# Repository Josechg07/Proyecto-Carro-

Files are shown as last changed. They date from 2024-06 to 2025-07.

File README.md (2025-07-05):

# SONICAR
# Logbook

This repository contains information about the sonicar team's robot for the 2025 World Robot Olympiad (WRO) Future Engineers competition. The design of the robot was taked from thingiverse, but was adapted to the necesities of the team.

# Team

### José Ricardo Chacón

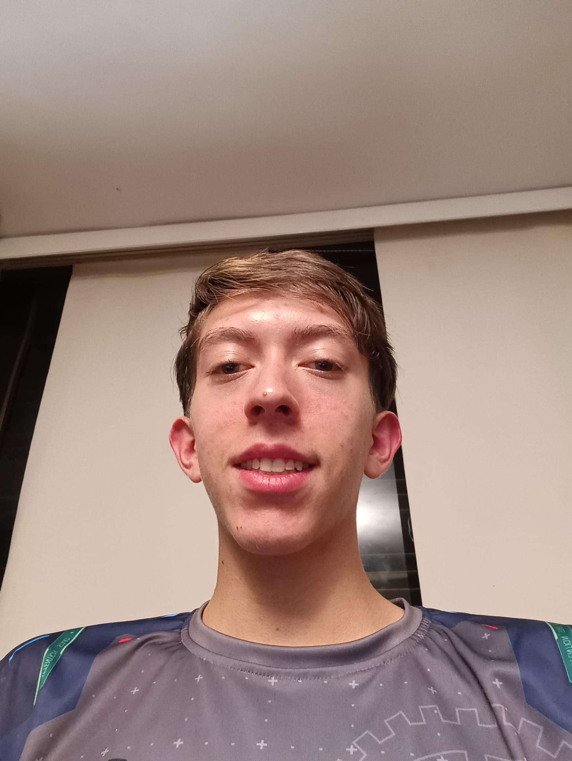
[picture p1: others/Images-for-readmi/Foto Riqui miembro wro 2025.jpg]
Photo member José Ricardo Chacón


Hey there!! I'm José Ricardo from Venezuela. This is my second time participating in the WRO on the Future Engineers category and this have been too much amazing!! On the first time, last year, my team and I got the opportunity to go to the competition on Italy because we got the first place in the regional leaderboard. This is an entire new experience, even that is the second time!! Creating this tipe of robot, obtaining new knowledge, meeting new people, is an incredible experience that I love. Is incredible what we can obtain with this tipe of challenges, and I'm ready to beat this!! Also, I like F1, cars, robots, program, and the tennis.

### Andrés José Casenave

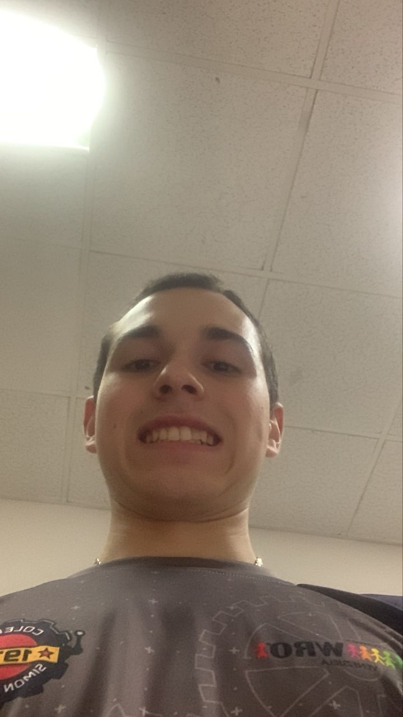
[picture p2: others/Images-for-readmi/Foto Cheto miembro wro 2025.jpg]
Photo member Andrés José Casenave


Hello! I’m Andrés from Venezuela, and this is my second time participating in the WRO Future Engineers category. Last year, my team and I got first place in the regional leaderboard. We qualified for the National Contest, where we had the opportunity to meet new people and see their way of confronting the challenge. I like robotics, cars, motorcycles, and basically anything with an engine on it.

### Juán Andrés Perez

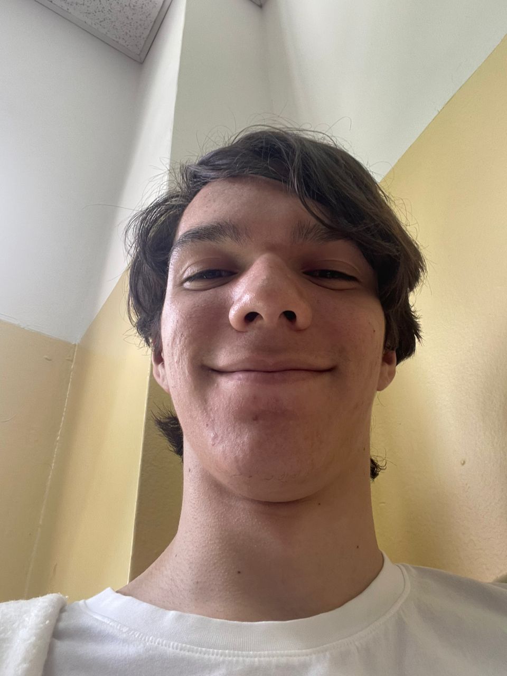
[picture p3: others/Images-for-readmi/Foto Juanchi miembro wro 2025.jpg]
Photo member Juán Andrés Perez


Hey, I'm Juan Pérez from Venezuela! This is my first time joining the WRO on the Future Engineers category and I am having a blast! I had never tried it before, but after starting, creating this robot has been an amazing experience. I love challenging myself! From crosswords to chess, you name it, and this whole experience feels like an even bigger challenge I'm ready to beat!

# Photo Team

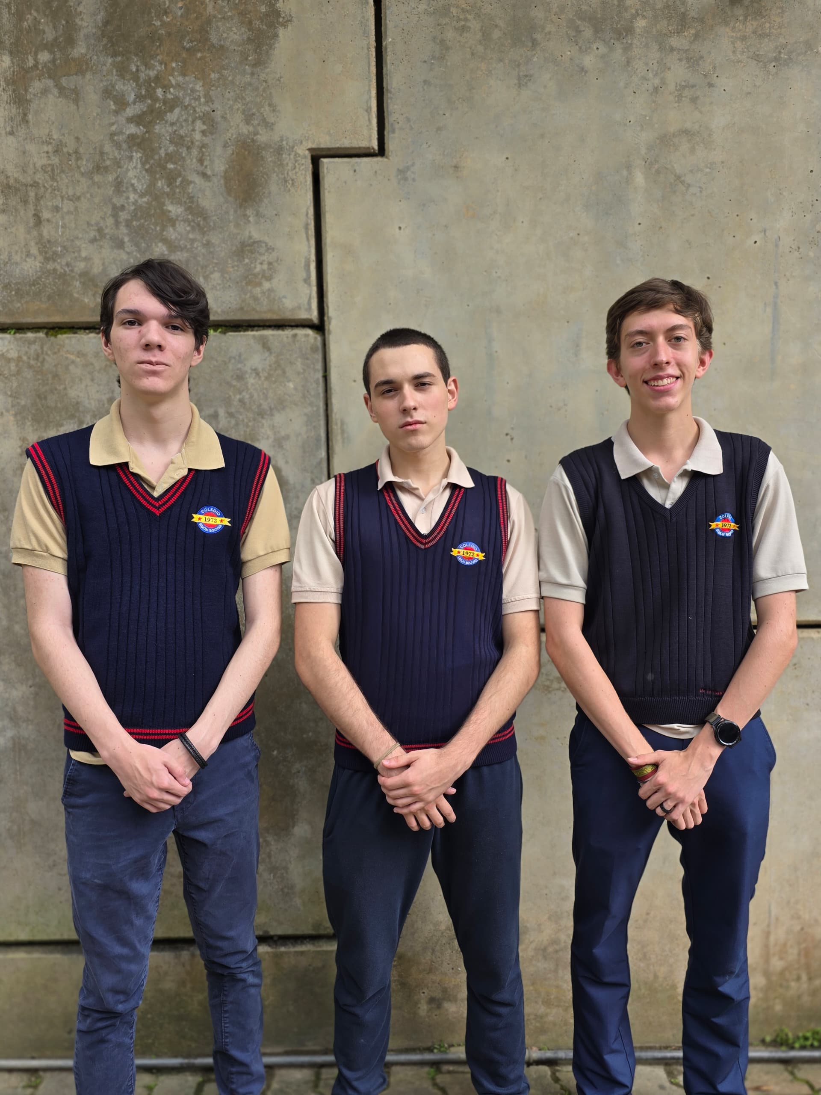
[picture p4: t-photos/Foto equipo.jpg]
Photo Team


# Challenge
The WRO 2024 Future Engineers – Autonomous Vehicle Challenge invites participants to conceptualize, construct, and program a robotic car capable of navigating a race track without human intervention. The layout of the track changes each round, requiring the robot to adapt in real-time. The challenge is divided into two core components: completing multiple laps while avoiding randomly placed obstacles, and executing an accurate parallel parking maneuver.

Participants are encouraged to apply advanced engineering principles including computer vision, sensor integration, and motion control, with a strong emphasis on innovation, precision, and system reliability.

This competition highlights essential stages of the engineering cycle, such as:

- Vehicle Dynamics: Designing effective and reliable mobility systems.

- Obstacle Navigation: Implementing strategies to identify and respond to traffic markers (red and green indicators) in compliance with event rules.

- Project Documentation: Demonstrating the development process, design rationale, and teamwork through transparent and collaborative repositories, such as GitHub.

Teams are evaluated not only on their robot's performance during the rounds but also on the clarity and depth of their engineering documentation and the ingenuity of their solution. The challenge aims to spark interest in STEM fields by offering hands-on experience in robotics, problem-solving, and collaborative innovation.

Discover more about the challenge by visiting the official site, or [*here*](https://wro-association.org/wp-content/uploads/WRO-2025-Future-Engineers-Self-Driving-Cars-General-Rules.pdf)

# Photos of the robot eustakio

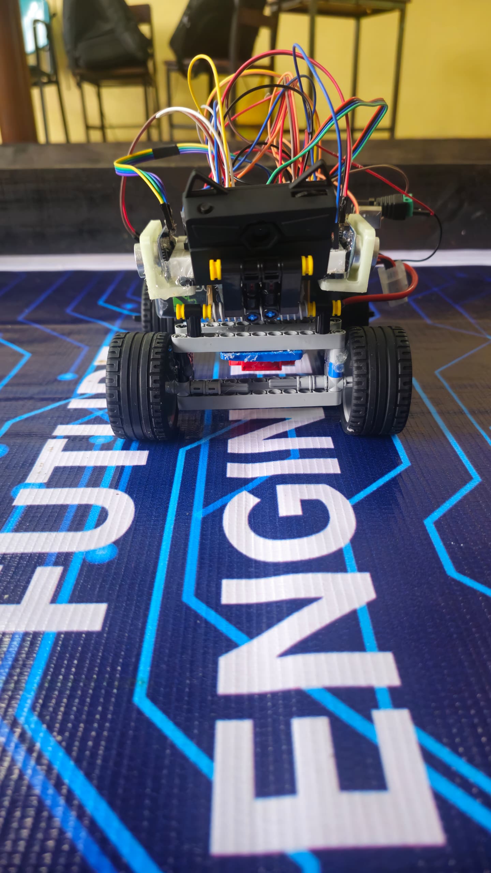
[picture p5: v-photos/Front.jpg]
Front
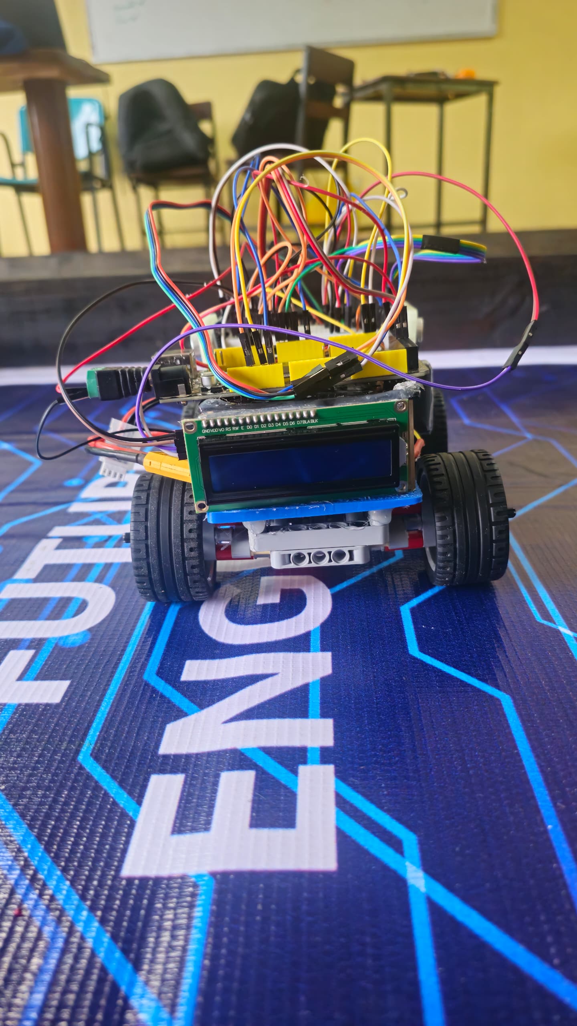
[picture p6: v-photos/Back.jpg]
Back
|  |  |
|:--:|:--:|
| Front | Back |

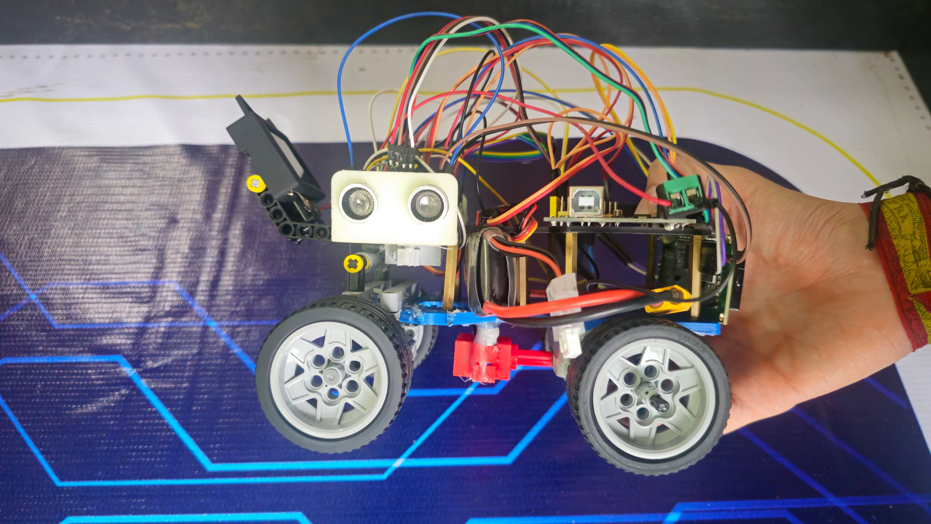
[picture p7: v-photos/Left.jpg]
Left
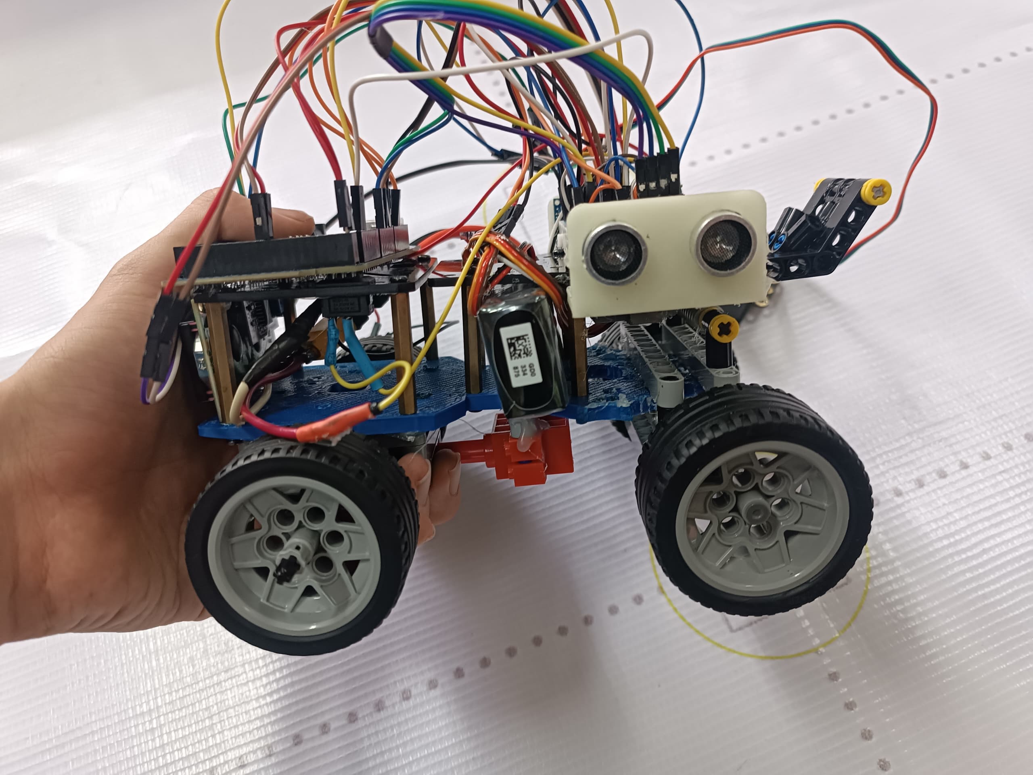
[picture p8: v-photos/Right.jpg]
Right
|  |  |
|:--:|:--:|
| Left | Right |

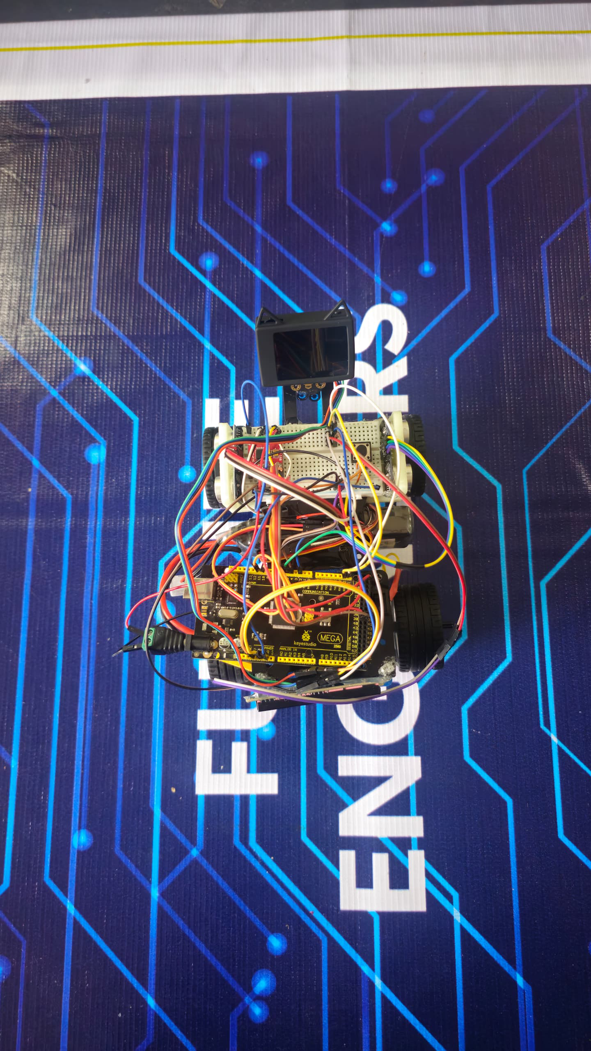
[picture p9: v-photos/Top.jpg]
Top
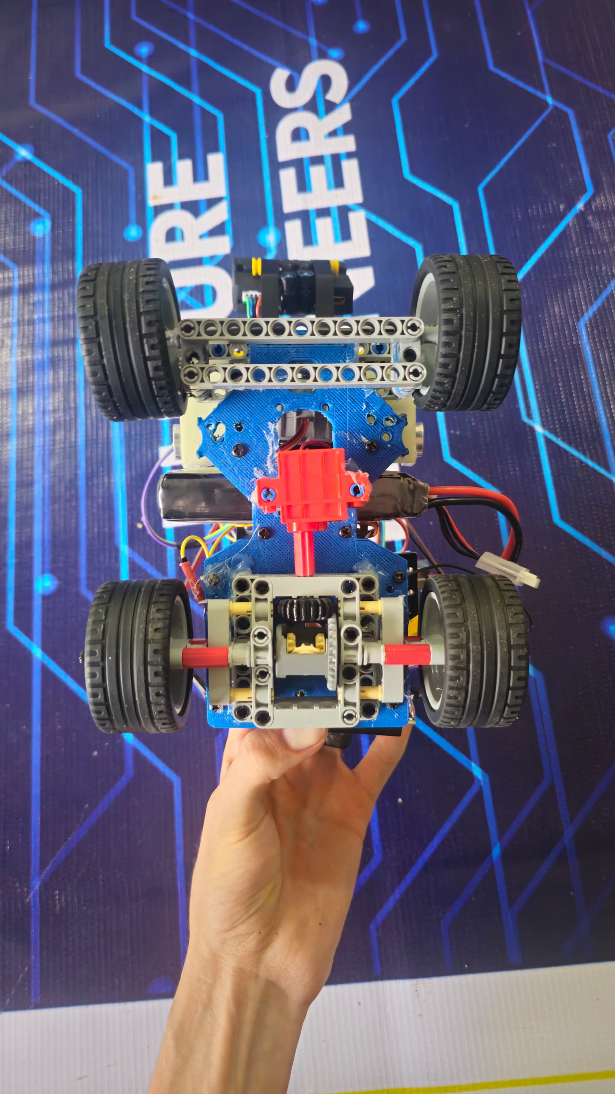
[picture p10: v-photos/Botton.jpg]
Botton
|  |  |
|:--:|:--:|
| Top | Botton |

# Video of our robot on: [*Youtube*](https://youtu.be/cRhCX8bQ4Iw)

# Mechanic Management

Desde la batería se derivan dos conductores: uno correspondiente al polo negativo (GND) y otro al polo positivo (V+). El conductor positivo está interrumpido por un interruptor mecánico, que actúa como un control de encendido, permitiendo o bloqueando el flujo de corriente hacia el resto del sistema.

Posterior al interruptor, el conductor se conecta al terminal VM (Voltage Motor) del puente H, responsable de alimentar los motores. Desde esta misma línea de alimentación, se deriva una conexión hacia el pin VIN del Arduino, que permite suministrar energía a la placa. El conductor negativo de la batería se conecta directamente al pin GND del Arduino, cerrando así el circuito de alimentación de la placa.

Adicionalmente, en el puente H se conecta un pin de alimentación (VCC) hacia la línea positiva de la protoboard para alimentar los componentes de lógica interna del puente.

El puente H dispone de tres pines de control: PWM A, IN1 e IN2.

PWM A está conectado al pin digital 10 del Arduino y permite la modulación por ancho de pulso (PWM) para el control de velocidad.

IN1 e IN2, conectados a los pines 12 y 13 respectivamente, determinan la dirección de rotación del motor conectado al canal A.

Las salidas del puente H (OUT1 y OUT2) están conectadas directamente al motor de corriente continua. Estas salidas permiten controlar el sentido y velocidad del motor en función de las señales de entrada enviadas desde el microcontrolador.

Finalmente, el motor está acoplado a las ruedas mediante un eje común que atraviesa un sistema de diferencial mecánico, el cual optimiza la maniobrabilidad del vehículo en curvas, distribuyendo el par de manera eficiente entre las ruedas y reduciendo el desgaste prematuro de las mismas.

### Motor DC Lego

<table border="1" cellspacing="0" cellpadding="10">
  <tr>
    <td width="50%" align="center">
      
    </td>
    <td width="50%" valign="top">
      <b>Specifications:</b>
      <ul>
        <li><b>Voltage:</b> 4.8V</li>
        <li><b>Gear Ratio:</b> 1:48</li>
        <li><b>Speed:</b> 650 ± 31% rpm</li>
        <li><b>Torque:</b> 1.2 ± kg·cm</li>
        <li><b>Weight:</b> 30g</li>
      </ul>
    </td>
  </tr>
</table>

A direct current (DC) motor runs on DC power. In this project, it propels the vehicle. The motor’s speed and direction are controlled via the L298 module, allowing the car to move forward or backward as needed. DC motors are known for their simplicity and efficiency, making them a popular choice in robotics.

### Motor Driver

<table border="1" cellspacing="0" cellpadding="10">
  <tr>
    <td width="50%" align="center">
      
    </td>
    <td width="50%" valign="top">
      <b>Specifications:</b>
      <ul>
        <li><b>Power supply voltage:</b> VM = 15V max, VCC = 2.7-5.5V</li>
        <li><b>Output current:</b> lout = 1.2A (average) / 3.2 A (peak) </li>
        <li><b>Standby control to save power</b></li>
        <li><b>CW/CCW/short-brake/stop motor control modes</b></li>
        <li><b>Built-in thermal shutdown cirtuit and low-voltage</b></li>
      </ul>
    </td>
  </tr>
</table>

The L298N motor driver controls the speed and direction of a DC motor. It receives signals from the Arduino and translates them into commands that the motor can understand, allowing for precise propulsion control. The L298N is a dual H-Bridge driver capable of handling two DC motors, but this project only uses one. Its ability to handle high voltages and currents makes it ideal for small-scale robotic and car projects.

### Steering

### Servo Motor

<table border="1" cellspacing="0" cellpadding="10">
  <tr>
    <td width="50%" align="center">
      
    </td>
    <td width="50%" valign="top">
      <b>Specifications:</b>
      <ul>
        <li><b>Rotation angle:</b> 270° </li>
        <li><b>Operating speed:</b> 0.12 ± 20% sec/60° at 4.8V </li>
        <li><b>Stall torque:</b> 1.8 kg·cm (6V) </li>
        <li><b>Weight:</b> 12.5g </li>
      </ul>
    </td>
  </tr>
</table>

A servo motor is used to control the vehicle’s direction. Servos are precision motors that rotate to specific angles, ideal for tasks requiring accurate movements. In this project, the servo is used to steer the front wheels, allowing the vehicle to change direction when obstacles are detected. Servo motors are essential in robotics for their precise control.

### Chasis

Here are the top view of the internal and external measurements, and .stl file of the chassis 3D. The design of the robot was personalized for our necessities of the competition.

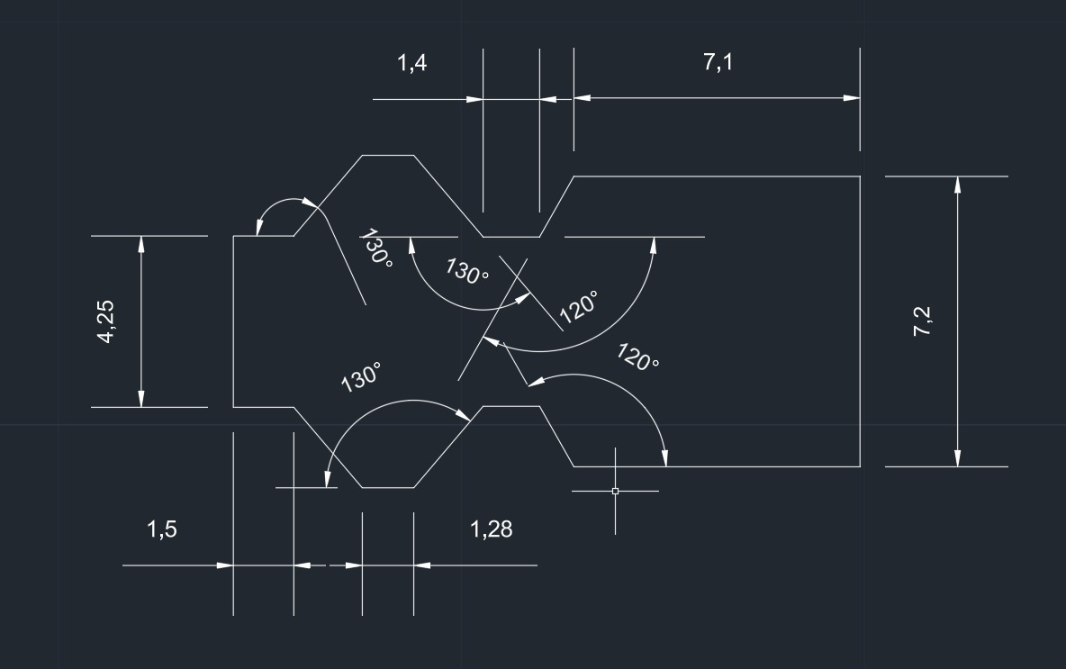
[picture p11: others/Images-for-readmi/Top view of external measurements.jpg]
Photo top view of the external measurements of the chassis 3D


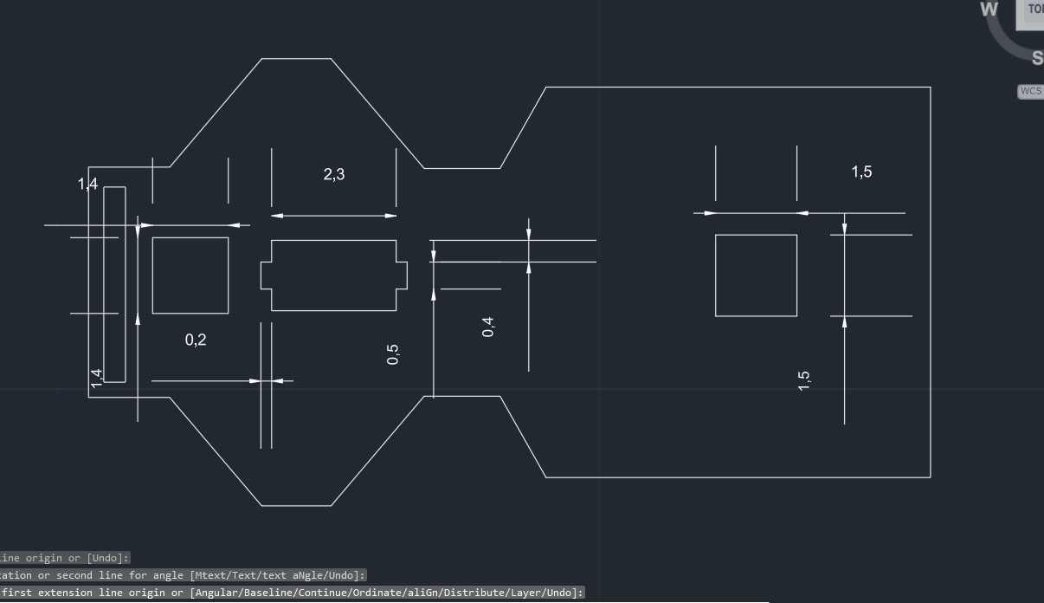
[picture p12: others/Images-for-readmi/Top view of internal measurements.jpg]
Photo top view of the internal measurements of the chassis 3D


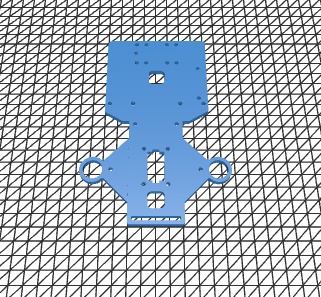
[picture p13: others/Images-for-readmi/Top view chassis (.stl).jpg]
Photo top view of the .stl file of the chassis 3D


### Creation of the Robot

Here are information about the process of creation of the robot of the team and images of the same:

Para armar el carro juntamos diversas piezas de distintas partes, algunas fueron diseñadas en 3D e impresas por nosotros, algunas pocas fueron timadas de kits de carros y otras piezas fueron armadas con LEGO. Originalmente el carro contaba con un sistema de giro con brazos rotulados a los extremos pero al ver que nos presentaba problemas en los giros cambiamos a un sistema con brazos impresos en 3D que posteriormente nos presentaron problemas debido a un punto muerto que tenían lo que permitía el giro libre de las ruedas haciendo que se tambaleara de un lado a otro y por último armamos un sistema de giro con LEGO que resultó ser más exacto y preciso al tomar curvas.

Para el sistema de potencia el carro contaba con un motor de DC  que iba conectado a un engranaje  que a su vez estaba conectado a un eje que se unía a las ruedas proporcionándoles la potencia necesaria para moverse; sin embargo, este sistema fue cambiado ya que el carro al ser muy pequeño y tener las ruedas muy grandes, en las curvas perdía velocidad y dejaba de avanzar, por lo que más adelante fue reemplazado por un sistema de propulsión en base a LEGO, en este sistema de agregó un diferencial mecánico lo que permitía a las ruedas traseras girar a distintas revoluciones, eliminando así el problema de la pérdida de velocidad en las curvas

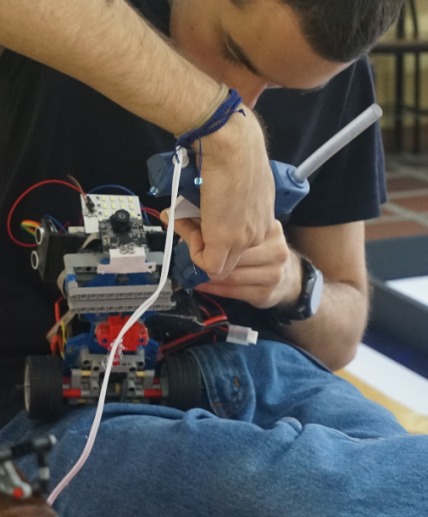
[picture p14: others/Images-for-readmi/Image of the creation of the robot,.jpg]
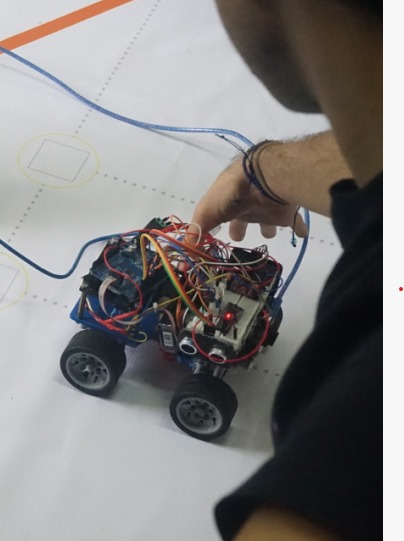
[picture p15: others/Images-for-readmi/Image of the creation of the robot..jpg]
|  |  |
|:--:|:--:|

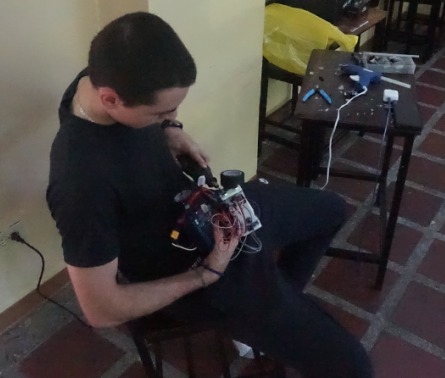
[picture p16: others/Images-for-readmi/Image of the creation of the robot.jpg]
|  |
|:--:|

# Mobility Management

El arduino mega es el cerebro del robot, se encuentra conectado con dos sensores de ultrasonido hc-sr04, uno a la derecha y otro a la izquierda, para poder medir los bordes, si la distancia que hay de uno de los dos lados es mayor a 1m, entonces ya el robot sabe si girar a la derecha o a la izquierda. Una vez determinada la dirección, se procede a mandar la información al servomotor para determinar si gira a la derecha o a la izquierda, aquí se le envía un ángulo determinado. A su vez, se le está enviando constantemente la información al motor DC para que el carro pueda avanzar constantemente. 

El robot cuenta con un giroscopio, el cual es capaz de determinar la velocidad angular y determinar una vez cuando el carro haya girado 90°, cuando lo hace, sigue en línea recta hasta llegar a la siguiente curva. Este ciclo se repite hasta que el carro cuente un total de 12 giros (4 giros por vuelta) y se detiene.

### Li-Po Battery 2200 mAH

A lithium battery was used to power the components, providing the current they need to operate. This battery has a large charge capacity and considerable voltage, which helps reduce the need for frequent recharges and increases work efficiency.

### Arduino Mega

<table border="1" cellspacing="0" cellpadding="10">
  <tr>
    <td width="50%" align="center">
      
    </td>
    <td width="50%" valign="top">
      <b>Specifications:</b>
      <ul>
        <li><b>Microcontroller:</b> Arduino Mega </li>
        <li><b>Pins:</b> 70 </li>
        <li><b>SRAM:</b> 8KB </li>
        <li><b>Frequency:</b> 16 MHz </li>
        <li><b>Flash memory:</b> 256 KB </li>
        <li><b>Input voltage:</b> 6-20V </li>
      </ul>
    </td>
  </tr>
</table>

### Camera Pixy

<table border="1" cellspacing="0" cellpadding="10">
  <tr>
    <td width="50%" align="center">
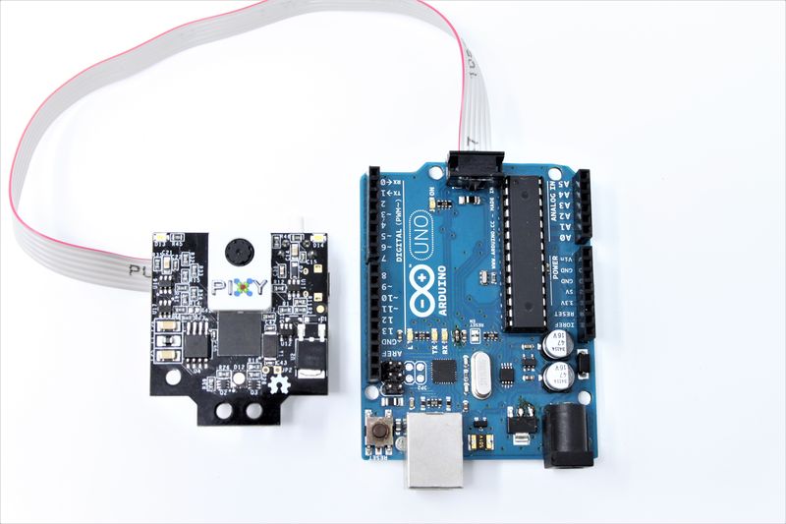
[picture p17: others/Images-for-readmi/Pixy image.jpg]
      
    </td>
    <td width="50%" valign="top">
      <b>Specifications:</b>
      <ul>
        <li><b>Microcontroller:</b> NXP LPC4330 </li>
        <li><b>RAM:</b> 264K bytes </li>
        <li><b>Resolution:</b> 1296 x 976 Pixels </li>
        <li><b>Flash memory:</b> 2M bytes </li>
        <li><b>Frame rate:</b> Up to 60 FPS </li>
        <li><b>Frequency:</b> 204 MHz (up to 800MHz) </li>
      </ul>
    </td>
  </tr>
</table>

### Laser Sensors (VL53L0X-V2)

<table border="1" cellspacing="0" cellpadding="10">
  <tr>
    <td width="50%" align="center">
      
    </td>
    <td width="50%" valign="top">
      <b>Specifications:</b>
      <ul>
        <li><b>Operating Voltage:</b> 2.6V - 5.5V </li>
        <li><b>Distance Range:</b> 3cm to 2m </li>
        <li><b>Field of View (FoV):</b> 25° </li>
        <li><b>Max Measurement Rate:</b> Up to 50 MHz </li>
        <li><b>Power Consumption:</b> 20 mW </li>
        <li><b>Dimensions:</b> 21mm x 13mm x 5 mm </li>
      </ul>
    </td>
  </tr>
</table>

Two VL53L0X-V2 laser sensors are used for distance measurement. These sensors detect object distances within a range by emitting a light beam and measuring the time it takes to return. This allows for object detection and autonomous movement. These sensors are commonly used in projects like this due to their precision and fewer problems compared to other types. In this work, they are crucial to achieving vehicle autonomy.

### Ultrasonic Sensor (HC-SR04)

<table border="1" cellspacing="0" cellpadding="10">
  <tr>
    <td width="50%" align="center">
      
    </td>
    <td width="50%" valign="top">
      <b>Specifications:</b>
      <ul>
        <li><b>Operating Voltage:</b> 5.5V DC </li>
        <li><b>Distance Range:</b> 2cm to 4m </li>
        <li><b>Field of View (FoV):</b> 15° </li>
        <li><b>Max Measurement Rate:</b> 20 MHz </li>
        <li><b>Power Consumption:</b> 15 mA </li>
        <li><b>Dimensions:</b> 45mm x 20mm x 15 mm </li>
      </ul>
    </td>
  </tr>
</table>
The HC-SR04 ultrasonic sensor is used for obstacle detection. It measures the distance to nearby objects by emitting an ultrasonic pulse and measuring the time it takes to bounce back. The distance is calculated based on the time the sound travels to the object and back. These sensors are widely used in robotics due to their precision and low cost and are fundamental to this project’s navigation capabilities.

### Protoboard

<table border="1" cellspacing="0" cellpadding="10">
  <tr>
    <td width="50%" align="center">
      
    </td>
    <td width="50%" valign="top">
      <b>Specifications:</b>
      <ul>
        <li><b>Tie-Points:</b> 830 (full-size) </li>
        <li><b>Dimensions:</b> 165mm x 55mm x 10mm </li>
        <li><b>Pitch (Hole SPacing):</b> 2.54mm (0.1 inch) </li>
        <li><b>Voltage Rating:</b> Up to 12V DC (recommended) </li>
        <li><b>Current Rating:</b> Up to 1 A (ideal < 500 mA per line) </li>
        <li><b>Wire COmpatibility:</b> 22-28 AWG solid-core jumper wires </li>
      </ul>
    </td>
  </tr>
</table>

## Energy Consuption

Hablando del consumo energético, el Arduino para poder operar, funciona con 5V y con aproximadamente 50 mA. Los dos sensores de ultrasonido (HC-SR04), consumen 5V y 15 mA cada uno, por lo que entre los dos suman un total de 30 mA. El giroscopio MPU6050 consume unos 4 mA, el motor DC (bajo carga moderada) consume cerca de 250 mA, el servomotor (SG90) en movimiento consume un promedio de 100 mA y la cámara Pixy consume unos 140 mA.
En teoría, si todos los componentes funcionaran simultáneamente a su consumo típico, la suma total sería de 574 mA (50+30+4+250+100+140), lo que se traduce a un total de 2.87 vatios (P = V \times I \Rightarrow 5V \times 0.574A = 2.87W).
Este es un cálculo teórico, ya que no todos los componentes están funcionando en simultáneo. Por ejemplo, primero se activa un sensor de ultrasonido por 20-30 milisegundos, se apaga, y luego se activa el otro. Lo mismo ocurre con el servomotor y los motores DC, que no están girando constantemente.
Considerando que la batería tiene una capacidad de 2200 mAh, se tendría una duración teórica máxima de aproximadamente 3.8 horas o 230 minutos (2200 \text{ mAh} / 574 \text{ mA} \approx 3.8 \text{ h}). Esta es una estimación optimista, ya que el consumo real varía constantemente dependiendo de las condiciones de la pista, la fricción y la frecuencia de uso de los motores, lo que podría reducir la autonomía.

Información del Arduino:

<table border="1" cellspacing="0" cellpadding="10">
  <tr>
    <td width="50%" align="center">
      <li><b>Arduino</b></li>
    </td>
    <td width="50%" valign="top">
      <ul>
        <li><b>Funciona con:</b> 5V </li>
        <li><b>Aproximadamente:</b> 50mA </li>
      </ul>
    </td>
  </tr>
</table>

Información sobre todos los componentes:

<table border="1" cellspacing="0" cellpadding="10">
  <tr>
    <td width="50%" align="center">
      <li><b>Sensor Ultrasonido (HC-SR04)</b></li>
    </td>
    <td width="50%" valign="top">
      <ul>
        <li><b>Funciona con:</b> 5V </li>
        <li><b>Aproximadamente:</b> 15mA </li>
        <li><b>Consumo entre ambos sensores: </b> 30mA</li>
      </ul>
    </td>
  </tr>
    <tr>
    <td width="50%" align="center">
      <li><b>Giroscopio (MPU6050)</b></li>
    </td>
    <td width="50%" valign="top">
      <ul>
        <li><b>Aproximadamente:</b> 4mA </li>
      </ul>
    </td>
  </tr>
  <tr>
    <td width="50%" align="center">
      <li><b>Motor DC</b></li>
    </td>
    <td width="50%" valign="top">
      <ul>
        <li><b>Aproximadamente:</b> 250mA </li>
      </ul>
    </td>
  </tr>
  <tr>
    <td width="50%" align="center">
      <li><b>Servo Motor (SG90)</b></li>
    </td>
    <td width="50%" valign="top">
      <ul>
        <li><b>Aproximadamente:</b> 100mA </li>
      </ul>
    </td>
  </tr>
  <tr>
    <td width="50%" align="center">
      <li><b>Cámara Pixy</b></li>
    </td>
    <td width="50%" valign="top">
      <ul>
        <li><b>Aproximadamente:</b> 140mA </li>
      </ul>
    </td>
  </tr>
</table>

<table border="1" cellspacing="0" cellpadding="10">
  <tr>
    <td width="50%" align="center">
      <li><b>Consumo Total:</b></li>
    </td>
    <td width="50%" valign="top">
      <ul>
        <li><b>574mA: </b> 50+30+4+250+100+140</li>
        <li><b>Total:</b> 2.87 vatios (P = V \times I \Rightarrow 5V \times 0.574A = 2.87W).</li>
      </ul>
    </td>
  </tr>
</table>

## Connection Diagram

Here is a driagram about the conection of each component to the arduino =, showing the path of the cables of each one.

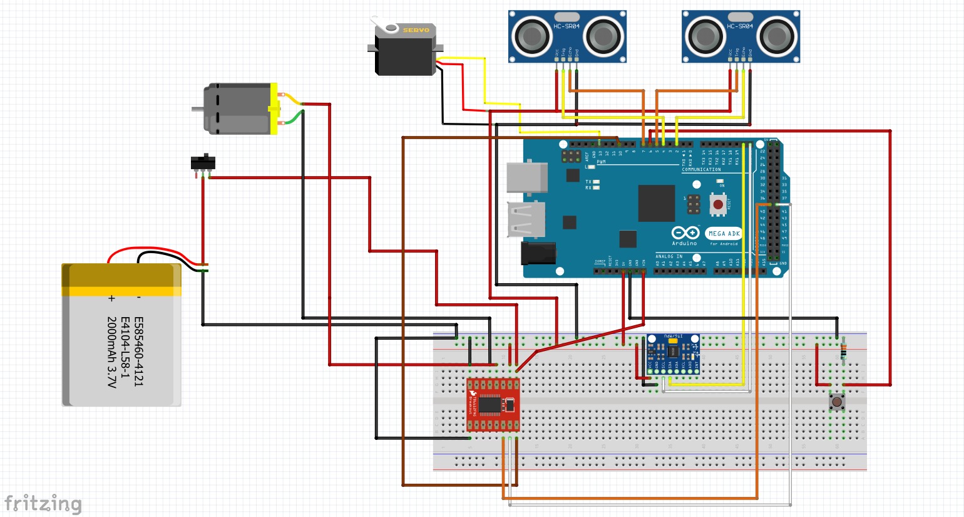
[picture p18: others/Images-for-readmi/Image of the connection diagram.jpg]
Photo of the Connection Diagram
|  |
|:--:|
| Connection Diagram |

# Code for each one of the component

## DC Motor

Given the fact that the Arduino has an ESP chip, the PWM signals have to be sent using the ( ```ledc``` ) utility.

```ino
void crotolamo() { // Void para que avance el carro
  giro.write(recto); // Poner ruedas rectas
  analogWrite(en, vel); // Poner la velocidad normal
  digitalWrite(in1, HIGH); // El carro avanza
  digitalWrite(in2, LOW);
}
void retroceder() { // Void para que el carro retroceda
  giro.write(recto); // Poner ruedas rectas
  analogWrite(en, vel); // Poner velocidad normal
  digitalWrite(in1, LOW); // El carro retrocede
  digitalWrite(in2, HIGH);
}
void permatrago() { // Void para que el carro se detenga
  giro.write(recto); // Poner ruedas rectas
  analogWrite(en, 0); // Poner la velocidad en 0
  digitalWrite(in1, LOW); // El carro no avanza ni retrocede
  digitalWrite(in2, LOW);
}
```

## Servo Motor

```ino
void gd() { // Void para que el carro gire a la derecha
  digitalWrite(LED_BUILTIN, HIGH); // Prender el led del Arduino para mostrar el giro
  analogWrite(en, vel); // Aumentar la velocidad del carro
  digitalWrite(in1, HIGH); // Asegurarse que el carro avanza
  digitalWrite(in2, LOW);
  giro.write(120); // Rotar las ruedas para que gire a la derecha
  while (derecha > 60) { // Parar el giro cuando se cumplan ciertas distancias
    sd(); // Continuar leyendo los valores
    delay(20);
  }
  crotolamo(); // Reiniciar el carro
  digitalWrite(LED_BUILTIN, LOW); // Indicar que acabo el giro
  rosamelano = millis(); // Guardar el tiempo en el que termina el giro
}
void gi() { // Void para que el carro gire a la izquierda
  digitalWrite(LED_BUILTIN, HIGH); // Prender el led del Arduino para mostrar el giro
  analogWrite(en, vel); // Aumentar la velocidad del carro
  digitalWrite(in1, HIGH); // Asegurarse que el carro avanza
  digitalWrite(in2, LOW);
  giro.write(65); // Rotar las ruedas para que gire a la izquierda
  while(izquierda > 60){ // Parar el giro cuando se cumplan ciertas distancias
    si(); // Continuar leyendo los valores
    delay(20); 
  }
  crotolamo(); // Reiniciar el carro
  digitalWrite(LED_BUILTIN, LOW); // Indicar que acabo el giro
  rosamelano = millis(); // Guardar el tiempo en el que termina el giro
} 
```

# Obstacle Management

### Open Round

La estrategia para la ronda abierta se fundamenta en el uso combinado de sensores de ultrasonido y un giroscopio.
Los sensores de ultrasonido son los encargados de la navegación principal. Su función es doble: primero, identifican los muros para determinar si el robot debe girar a la derecha o a la izquierda; segundo, detectan si el vehículo se acerca demasiado a una pared para corregir la trayectoria y evitar colisiones.
Por su parte, el giroscopio garantiza la precisión en los movimientos. Cuando los sensores de ultrasonido indican la necesidad de un giro, el giroscopio mide la velocidad angular para asegurar una rotación exacta de 90 grados. Esto es crucial para que el robot mantenga una trayectoria recta después de cada giro.
Inicialmente, enfrentamos una dificultad: al depender únicamente de los ultrasonidos para evitar paredes, el robot a veces sobrerreaccionaba con múltiples giros pequeños, provocando que avanzara en diagonal. La incorporación del giroscopio fue clave para solucionar este problema, ya que estabilizó la trayectoria y eliminó los giros innecesarios.
El ciclo de navegación se completa de la siguiente manera: el robot realiza un total de 12 giros de 90 grados, lo que equivale a 3 vueltas completas en un circuito de cuatro esquinas. Al finalizar la tercera vuelta, el vehículo avanza un tramo corto y se detiene para concluir la prueba.

### Final Round

### Cube Detection

Para la estrategia de esquivar obstáculos, contamos con una cámara husky lens, la cual nos permite identificar el color de los obstáculos, ya sea rojo o verde. Para determinar si el objetivo se encuentra cerca o lejos, usamos la información que nos proporciona la cámara, como lo es el ancho y alto, en píxeles, del objeto, si el área es pequeña, sabemos que el obstáculo está lejos, lo que permite que el carro pueda esquivarlo desde lejos. Pero si el obstáculo se encuentra cerca, el carro retrocede (para evitar chocar) y luego lo esquiva por su lado correspondiente. Esta lógica se mezcla con la de la primera ronda para poder lograr las 3 vueltas sin problema alguno.

### Parking Wall Detection

### Robot Construction Guide

### Cost List

# Installation :books:
### System Requirements
* [Beak](https://beakit.com/)


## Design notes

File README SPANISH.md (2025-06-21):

# SONICAR
# Bitácora

Nosotros, Andrés Casenave, José Chacón y Juán Perez, somos estudiantes de 5to año y 4to año del Colegio Simón Bolívar II. Al conocer de este concurso nos constituimos como un equipo de trabajo con el sueño de aprender sobre esta competencia, conocer a nuevas personas, trabajar juntos para cumplir un objetivo y representar al colegio. Sin embargo, nuestros conocimientos eran limitados y representó un gran reto para nosotros adquirir todas las destrezas que exigía este concurso, por lo que solicitamos ayuda a nuestros entrenadores para adquirir conocimientos tanto de diseño, robótica, mecánica, electrónica y programación. Han sido unos arduos meses de trabajo y estudio para resolver cada uno de los retos que impone tener un carro autónomo.

Al inicio del proyecto, al ya tener conocimiento por nuestra competencia se nos fue más sencillo el realizar el código del robot. Aún así, nos encontramos con varios inconvenientes ya que al tener tiempo sin realizar cambios en este y nutrirnos de conocimiento, tuvimos que volver a aprender sobre el código. La parte positiva es que al ya contar con conocimiento, fue más fácil el entender el código y el funcionamiento del robot, lo que también facilito los futuros arreglos que requeriría el robot.

Los primeros meses nos enfocamos en el entendimiento de nuestro antiguo código y realizar un nuevo diseño del carro usando el programa de AutoCAD como herramienta principal, pero posteriormente empezamos a utilizar blender ya que es más versatil para realizar las figuras; y una vez finalizado el diseño procedimos a imprimirlo en 3D en la impresora del colegio. Luego pasamos a ensamblar las piezas e ir probándolas para su correcto ensamblaje y la coordinación de estas con el resto de los componentes que debía tener el carro. Los meses pasaron y el carro iba avanzando, siendo sometido a varios cambios durante el proceso entre los que se incluyen la distribución de los diferentes componentes. Finalmente logramos que funcionara y allí comenzamos con la programación del mismo, utilizando un Arduino Mega como cerebro del robot.

Nuestros primeros inconvenientes se presentaron al momento de volver a probar el robot, ya que nos presento nuevos problemas como por ejemplo, que las pilas que estábamos utilizando se empezaron a inflar, lo que nos preocupó mucho y nos obligó a ver otras opciones de batería para evitar cualquier inconveniente. Al comprar las nuevas pilas nos dimos cuenta que nos hacía falta un conector para que lograra tener contacto hacia el L298N, por lo que terminamos haciendo más compras de lo planeado y terminó retardando el proceso de creación del robot.

Luego, empezamos a probar nuevos componentes que nos pudieran dar con mejor exactitud las medidas de los sensores para que el robot trabaje de mejor manera. Igualmente al implementar estos componentes, algunos nos terminaron ayudando bastante como algunos nos terminaron dando muchos más inconvenientes que los que ya teníamos.

Al ver todos los inconvenientes que teníamos con el carro, tomamos la decisión de crear uno nuevo, por lo que nos terminamos basando en un diseño ya creado y montado en "thingiverse" y le realizamos cambios a su estructura para lograr adaptarla a nuestras necesidades del carro. Esto nos ayudo a tener un robot personalizado, mejor adaptado para la competencia, y ya teniendo una buena base del diseño nos aseguraba una buena distribución de los componentes. Esto nos presentó com un ligero retardo ya que fue casi como empezar de cero, pero nos ayudó a tener una mejor estructura.

Al tener que adaptarnos a una nueva estructura, fue un poco desafiante al momento de ingresar el sistema de giro ya que eran dimensiones distintas. Ya teniendo los componentes conectados, empezaron unos nuevos problemas. Estos mayormente fueron por los cables, obligándonos a buscar soluciones para mantener a los cables unidos entre sí y a los componentes. Mientras resolvíamos estos inconvenientes, se nos presentaron otros problemas como  de comunicación de los componentes a la placa, problemas con el código, entre muchos otros; pero igualmente logramos resolver cada uno de estos inconvenientes que se nos fueron presentando.

Dentro de poco tenemos nuestra primera competencia y estamos nerviosos por los errores que nos da el robot que aparecen de un momento a otro, pero gracias a todo nuestro equipo y a nuestros coachs, podemos aprender sobre nuestros errores para mejorar para las siguientes competencias e incluso superar los desafios que se nos tocara afrontar.

### Descripción del Proyecto
SONICAR es un proyecto de robótica desarrollado por estudiantes de bachillerato del Colegio Simón Bolívar II. El proyecto consiste en un vehículo autónomo capaz de navegar y evitar obstáculos utilizando un Arduino Mega. El vehículo emplea sensores de ultrasonido para detectar objetos en su entorno, un motor DC para la propulsión, un servo motor para la dirección y un módulo controlador de motor L298 para manejar el motor DC. Este proyecto proporciona una excelente oportunidad de aprendizaje en el campo de la robótica y la programación, integrando varios componentes y tecnologías para lograr su funcionalidad.

## Componentes Utilizados
### Lista de Materiales (BOM)
### 1. Estructura:
1.1 6x columnas principales 4cm x 0.4cm x 0.4cm 

1.2 Chasis 

1.3 Alambre

1.4 Silicón Caliente

1.5 Barra de conexión x 2

1.6 Tornillos x 19

1.7 Conector de Rueda x 2

1.8 Base de motor

### 2. Componentes Eléctricos:

2.1 Arduino Mega

2.2 L298N

2.3 Sensor de ultrasonido (Hc-sr04)

2.4 Sensores de Laser (VL53L0X-V2) x2

2.5 Varios cables macho-macho, hembra-hembra y macho-hembra

2.6 Pila de 5600mAH de litio

2.7 Protoboard sen

2.8 Cámara Huskylens

### 3. Componentes Mecánicos:

3.1 Ruedas x 4

3.2 Motor corriente directa (DC) 11V

3.3 Servomotor (SG90)

### Arduino Mega

El Arduino Mega es una placa de desarrollo de bajo costo, que permite realizar proyectos de programación y electrónica. Cuenta con un microcontrolador de 8 bits, capacidad de memoria limitada pero suficiente para muchos proyectos, y múltiples puertos para conectarse a otros componentes. En este proyecto, el Arduino Mega actúa como el cerebro del vehículo, tomando decisiones basadas en la información proporcionada por los sensores y controlando los motores. La simplicidad y versatilidad del Arduino Mega lo convierten en una plataforma ideal para proyectos educativos y de prototipado.

### Sensores Laser (VL53L0X-V2)

Se utilizan dos sensores lase VL53L0X-V2 para la medición de distancias. Estos sensores miden la distancia de objetos en un rango de distancia emitiendo un rayo de luz midiendo el tiempo que tarda entre su salida del componente hasta su regreso, permitiendo la detección de objetos y su desplazamiento de manera autónoma. Estos tipos de sensores son utilizados en este tipo de proyectos gracias a su precisión y menores inconvenientes comparados a otros sensores, y en este trabajo, son importantes para lograr la autonomía del vehículo.

### Pila de 5600mAH de litio

Se utilizó una pila de litio para lograr el funcionamiento de los componentes brindándoles corrientes para que puedan funcionar. Esta pila tiene una gran capacidad de carga y un voltaje considerable, lo que ayuda a evitar tener una gran cantidad de pilas y tener que cargarlas cada poco tiempo, volviendo mas eficiente el trabajo por ese aspecto.

### Sensor de Ultrasonido (HC-SR04)

Se utiliza un sensor de ultrasonido HC-SR04 para la detección de obstáculos. Estos sensores miden la distancia a objetos cercanos emitiendo un pulso de sonido ultrasonido y midiendo el tiempo que tarda en reflejarse. La distancia se calcula en función del tiempo que tarda el sonido en viajar hacia el objeto y regresar al sensor, permitiendo al vehículo detectar obstáculos y navegar de manera autónoma. Los sensores de ultrasonido son ampliamente utilizados en robótica debido a su precisión y bajo costo, y en este proyecto, son fundamentales para la capacidad de navegación del vehículo.

### Módulo Controlador de Motor (L298N)

El controlador de motor L298 permite controlar la velocidad y dirección de un motor de corriente continua (DC). Este módulo recibe las señales del Arduino y las traduce en comandos que el motor puede entender, permitiendo un control preciso de la propulsión del vehículo. El L298N es un controlador de motor dual H-Bridge que puede manejar dos motores DC, pero en este proyecto se utiliza solo uno. Su capacidad para manejar altos voltajes y corrientes lo hace ideal para proyectos de robótica y automóviles a pequeña escala.

### Motor DC

Un motor de corriente continua (DC) es un motor eléctrico que funciona con corriente directa. En este proyecto, el motor DC se utiliza para propulsar el vehículo. La velocidad y dirección del motor se controlan a través del módulo L298, permitiendo que el vehículo se mueva hacia adelante o hacia atrás según sea necesario. Los motores DC son conocidos por su simplicidad y eficiencia y son una opción popular para proyectos de robótica debido a su capacidad de control sencillo y su rendimiento fiable.

### Servo Motor

Un servo motor se utiliza para controlar la dirección del vehículo. Los servos son motores de precisión que pueden girar a posiciones específicas, lo cual es útil para aplicaciones que requieren movimientos precisos. En este caso, el servo motor se utiliza para girar las ruedas delanteras del vehículo, permitiendo que cambie de dirección cuando se detectan obstáculos. Los servo motores son esenciales en robótica por su capacidad de control preciso, lo que permite una dirección exacta y una navegación eficiente.

### Cables y Conectores

Se utilizan varios cables y conectores para interconectar todos los componentes del proyecto. Es importante utilizar cables de buena calidad y asegurar conexiones firmes para evitar problemas de comunicación y suministro de energía. Los cables y conectores adecuados garantizan que todos los componentes funcionen correctamente y se comuniquen de manera efectiva, lo cual es crucial para el rendimiento del vehículo.

### Integrantes del Equipo

El equipo responsable de este proyecto está compuesto por estudiantes de bachillerato del Colegio Simón Bolívar II, quienes han trabajado en colaboración para combinar sus habilidades en programación y electrónica:

•	José Chacón: José se encargó de la unificación del software con el hardware, desarrollando partes del código y amoldando el chasis del carro para un diseño mucho más de acuerdo a nuestras necesidades, al igual de asegurarse de que las señales se transmitan correctamente y que el sistema responda adecuadamente a los datos de los sensores. José también se encargó de mejorar el diseño del vehículo para tener un robot acorde las normativas tanto de peso, de distancia, al igual para un buen funcionamiento de los componentes.

•	Andrés Cazenave: Andrés se enfocó en la parte de hardware, asegurándose de que todos los componentes estuvieran correctamente conectados y funcionando adecuadamente. Su responsabilidad incluyó el montaje del circuito, la integración de los sensores, el motor y el controlador de motor, y la solución de problemas de hardware. Andrés también trabajó en la optimización del diseño del vehículo para asegurar una construcción sólida y eficiente, que pueda soportar el uso continuo y manejar diversas condiciones de operación.

•	Juán Perez: Juán trabajó en la parte del software, desarrollando el código que permite al vehículo tomar decisiones basadas en la información de los sensores y controlar los motores. Su trabajo incluye la programación en C++ para interactuar con los pines del Arduino y coordinar las acciones del vehículo. Juán igualmente trabajó en el diseño del vehículo para asegurar un mejor uso de los componentes.

## Descripción de los Módulos y su Relación con los Componentes Electromecánicos

### Módulos del Código

1.	Módulo de Sensores: Este módulo maneja la interacción con el sensor de ultrasonido y los sensores láser. Envía pulsos de disparo a los sensores y lee los pulsos de eco para calcular la distancia a los obstáculos. Los sensores láser envían rayos de luz y toman el tiempo que tarda en volver ese rayo para calcular la distancia de los objetos. Los datos de este módulo son cruciales para las decisiones de navegación del vehículo.

2.	Módulo de Control del Motor: Este módulo se encarga de la interfaz con el controlador de motor L298. Traduce comandos de alto nivel (como avanzar, retroceder, detenerse) en señales que controlan la velocidad y dirección del motor DC. Este módulo asegura un control preciso sobre la propulsión del vehículo.

3.	Módulo de Control del Servo: Este módulo controla el servo motor responsable de la dirección. Traduce los comandos direccionales en ángulos específicos para el servo, permitiendo que el vehículo gire sus ruedas delanteras de manera adecuada.

4.	Módulo de Control Principal: Este módulo integra los datos de los sensores y controla los módulos de motor y servo basándose en la lógica de navegación del vehículo. Es el cerebro central del vehículo, tomando decisiones sobre cómo moverse y girar basándose en las entradas de los sensores.

### Relación con los Componentes Electromecánicos

•	Sensores de Ultrasonido (HC-SR04): Estos sensores están conectados a los pines del Arduino Mega. El módulo de sensores envía señales de disparo a través de salidas y lee los ecos de retorno a través de entradas para calcular las distancias.

•	Motor DC y Controlador de Motor L298N: El módulo de control del motor envía señales desde los pines del Arduino Mega al controlador de motor L298N, que luego controla el voltaje y la corriente suministrados al motor DC, dictando su velocidad y dirección.

•	Servo Motor: El módulo de control del servo envía señales PWM desde un pin del Arduino Mega al servo motor, ajustando su posición para dirigir el vehículo.
Proceso para Construir/Compilar/Cargar el Código

### Construcción del Vehículo

1.	Ensamblar el Hardware:

o	Conectar los sensores HC-SR04 a los pines adecuados en el Arduino Mega.
o	Conectar el controlador de motor L298N al motor DC y a los pines del Arduino.
o	Conectar el servo motor a un pin del Arduino para el control PWM.
o	Asegurarse de que todos los componentes estén conectados de manera segura y alimentados.

2.	Preparar el Arduino Mega:

o	Asegurarse de tener el software Arduino IDE instalado en tu computadora.
o	Conectar el Arduino Mega a la computadora mediante un cable USB.
o	Cargar el código de control en el Arduino Mega desde el Arduino IDE.

3.	Clonar el Repositorio:

o	Clonar el repositorio del proyecto SONICAR desde GitHub.

4.	Ejecutar el Código:

o	Asegurarse de que todos los scripts y módulos estén en su lugar.
o	Ejecutar el código cargándolo en el Arduino Mega utilizando el Arduino IDE.

### Compilación y Carga

•	Los scripts en Arduino no requieren compilación adicional fuera del entorno de desarrollo Arduino IDE.
•	Cargar directamente el código de control en el Arduino Mega desde el Arduino IDE.

# Installation :books:
### System Requirements
* [Beak](https://beakit.com/)


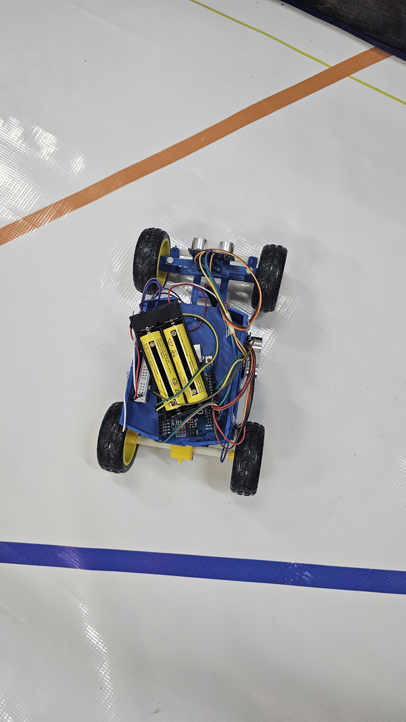
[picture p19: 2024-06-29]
v-photos/Arriba.jpg

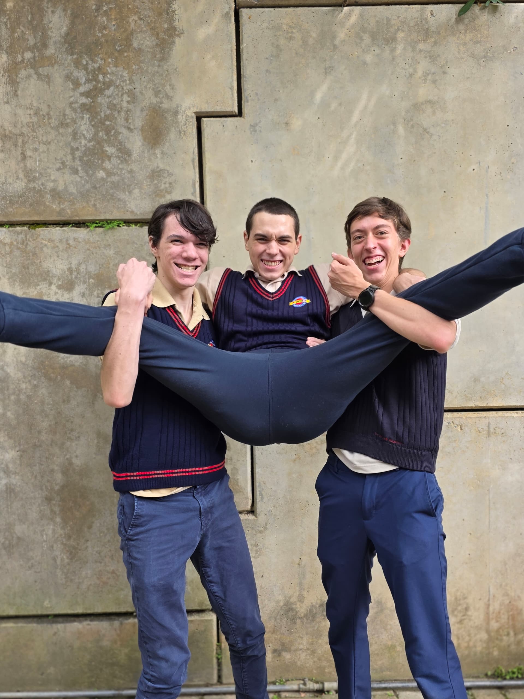
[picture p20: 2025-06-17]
t-photos/Foto loca equipo.jpg

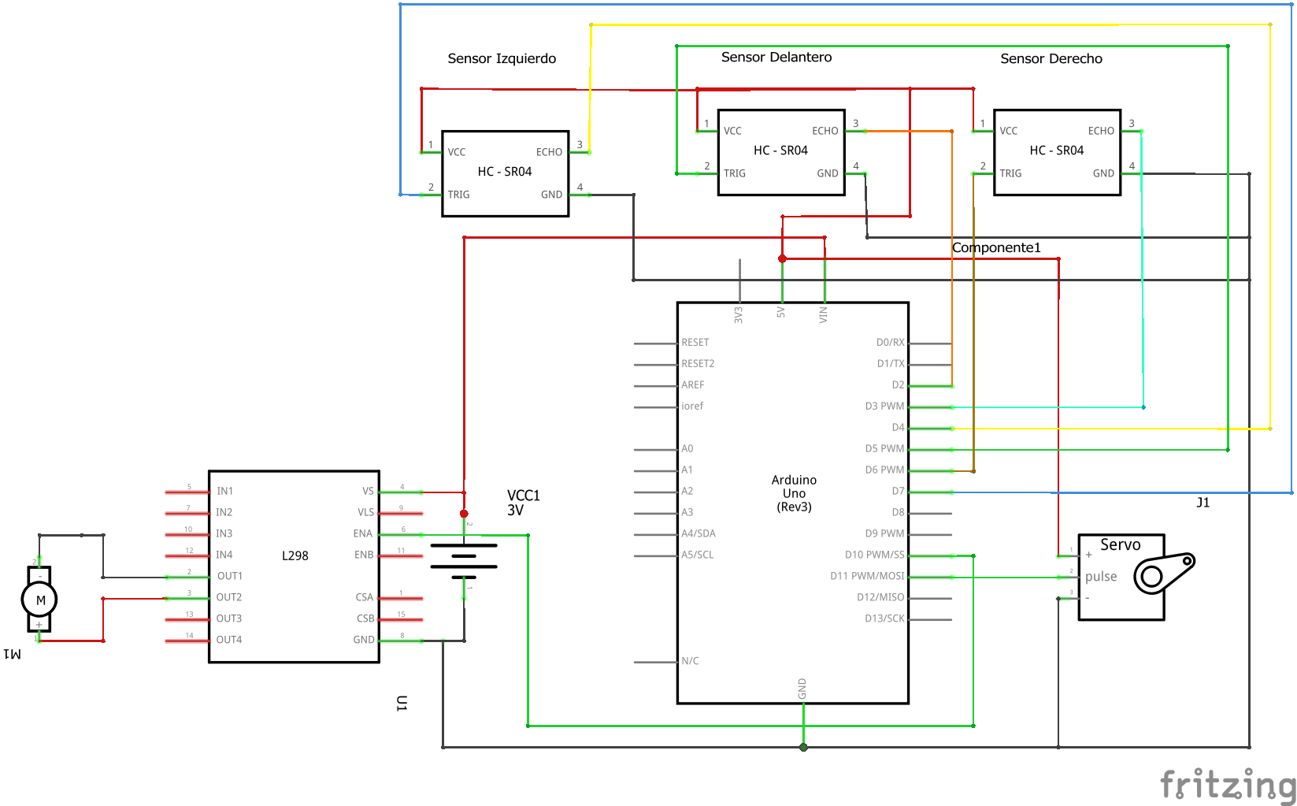
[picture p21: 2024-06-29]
schemes/sonicar_esquemático.png

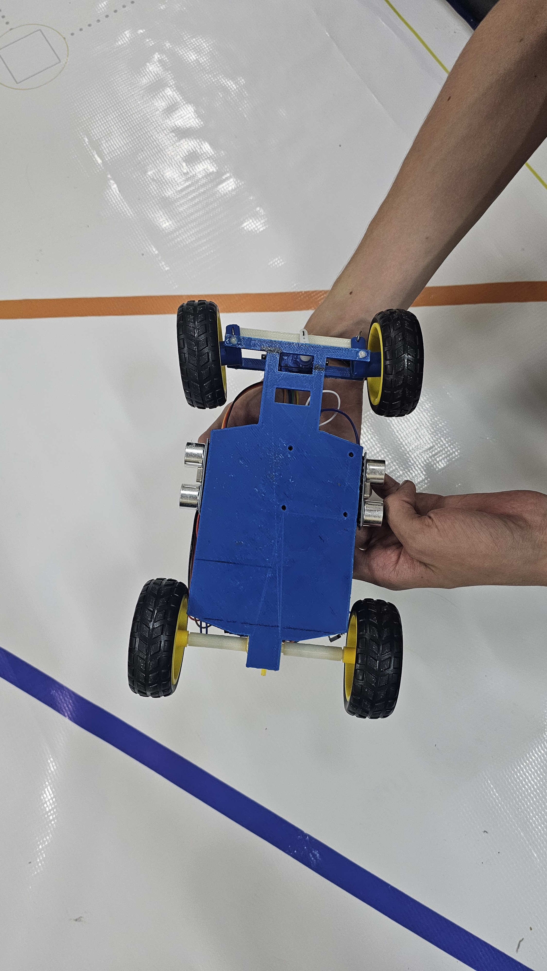
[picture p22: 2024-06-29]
v-photos/Debajo.jpg

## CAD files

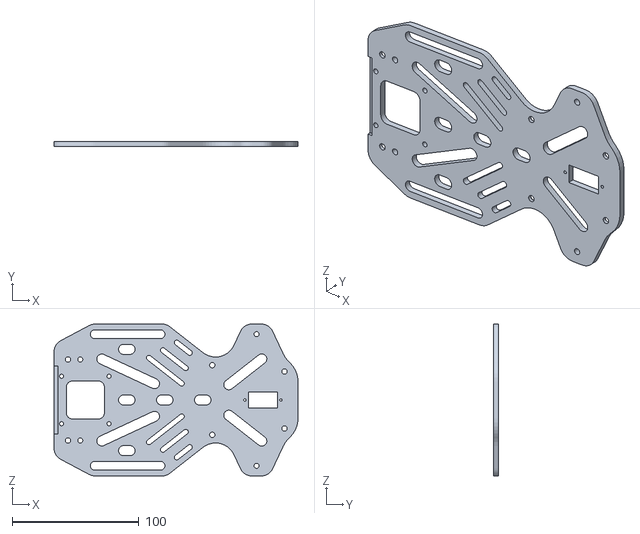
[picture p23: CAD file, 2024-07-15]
models/Partes carro #2/Chassis_CHANGE.STL
192.7 x 4.00 x 120.0

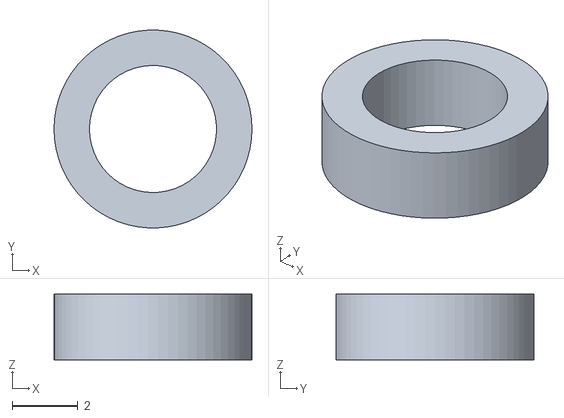
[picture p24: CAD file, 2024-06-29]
models/Partes carro/RCcar_7.stl
6.00 x 5.99 x 2.00

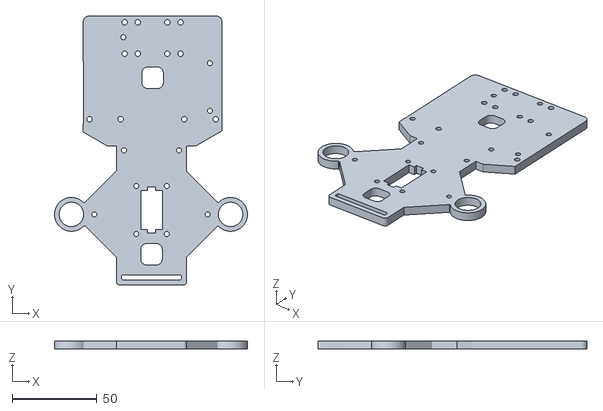
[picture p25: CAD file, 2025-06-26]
others/chasisprototipo2.stl
114.0 x 158.8 x 5.00

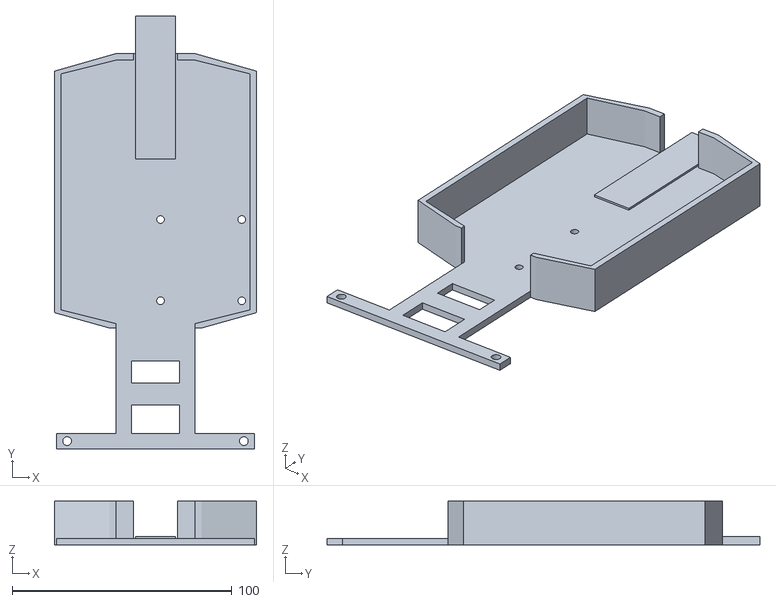
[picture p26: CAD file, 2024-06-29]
models/Partes carro/RCcar_5.stl
92.0 x 197.0 x 20.0

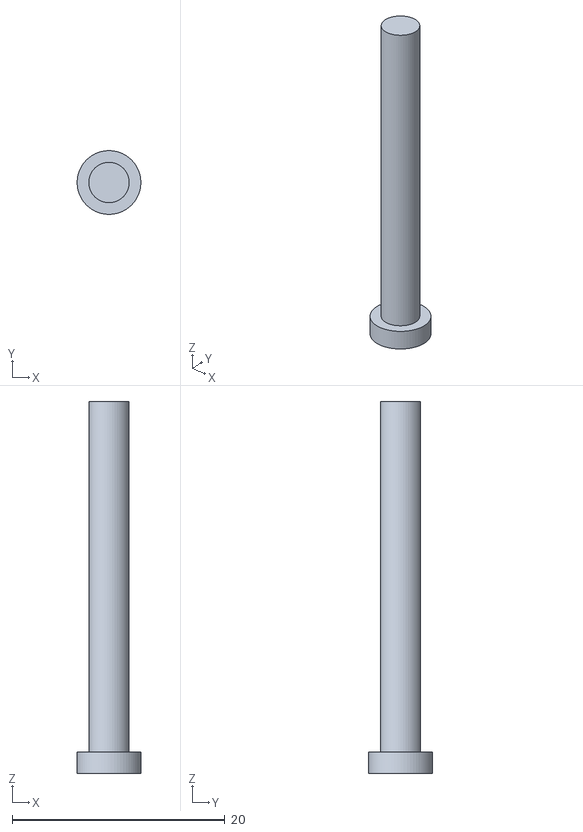
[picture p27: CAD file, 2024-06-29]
models/Partes carro/RCcar_6.stl
6.00 x 5.99 x 35.0

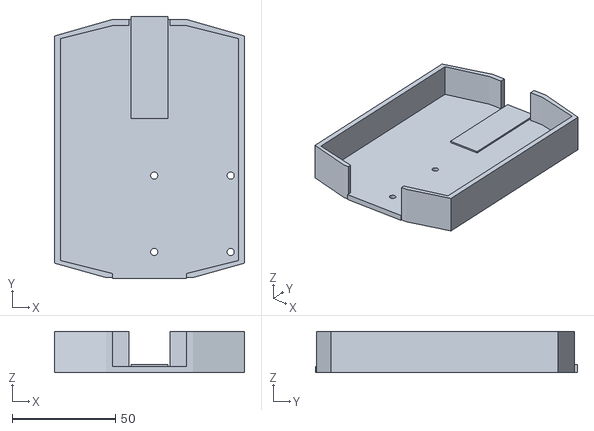
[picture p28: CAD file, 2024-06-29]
models/Partes carro/chasis_rc.stl
92.0 x 127.0 x 20.0

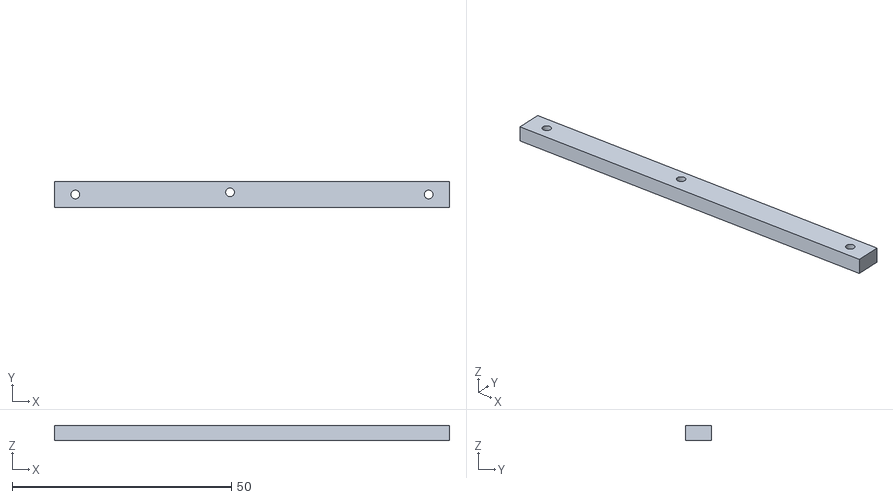
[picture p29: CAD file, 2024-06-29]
models/Partes carro/RCcar_4.stl
90.0 x 6.00 x 3.40

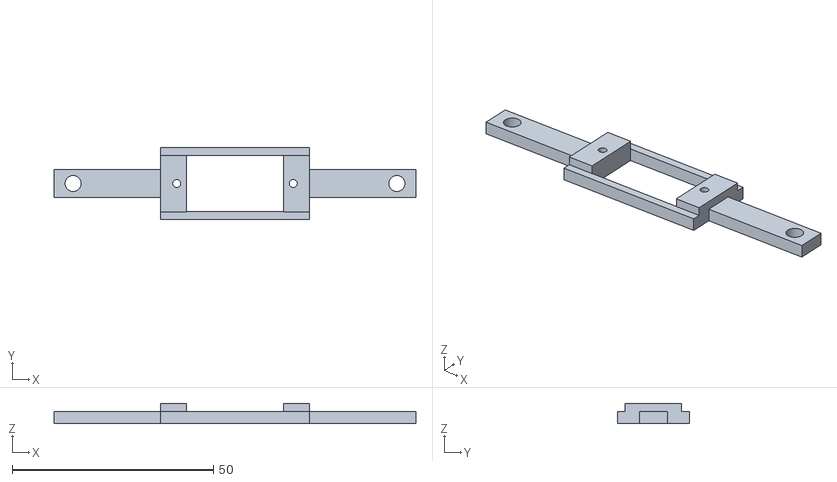
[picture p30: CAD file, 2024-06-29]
models/Partes carro/RCcar_3.stl
90.0 x 18.0 x 5.00

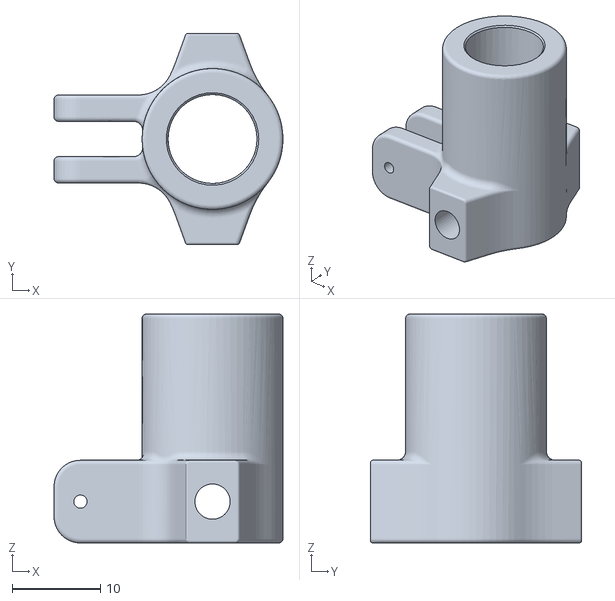
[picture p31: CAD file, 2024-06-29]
models/Partes carro/RCcar_2.stl
26.0 x 24.0 x 26.0

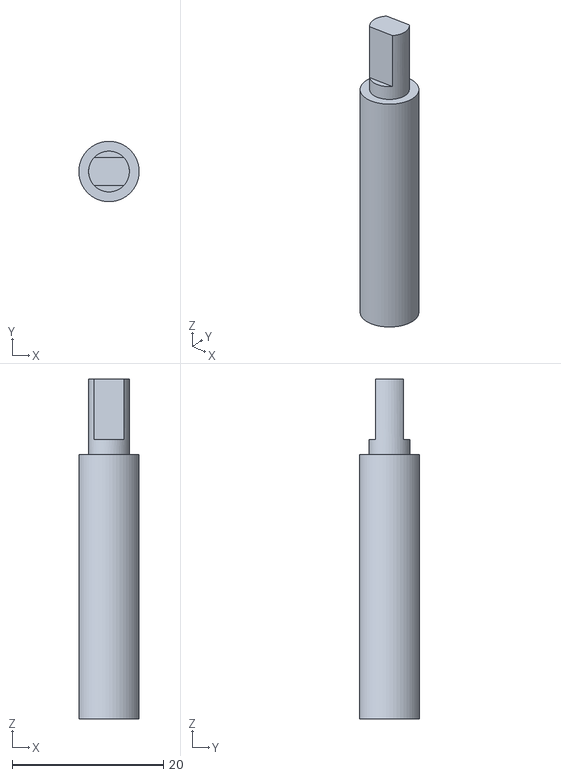
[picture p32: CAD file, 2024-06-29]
models/Partes carro/RCcar_8.stl
8.00 x 8.00 x 45.0

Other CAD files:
models/Partes carro/Planos carro #1.dwg

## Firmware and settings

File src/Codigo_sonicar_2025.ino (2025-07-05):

#include <NewPing.h>  // Para los sensores de ultrasonido
#include <Servo.h>    // Para el servomotor
#include <MPU6050.h>
#include <Wire.h>
#include <Pixy2.h>
Pixy2 pixy;
MPU6050 copio;
int16_t ax, ay, az;
int16_t gx, gy, gz;
const int in1 = A2;    // Pin IN1 del controlador de motor
const int in2 = 7;    // Pin IN2 del controlador de motor
const int en = 5;      // Pin ENA (PWM) para controlar la velocidad
const int servo = 10;  // Pin de señal del servo
const int td = 3;
const int ed = 2;
const int ti = 9;  // CAMBIADO: Estaba en el pin 13
const int ei = 4;
const int MPU = 0x68;
const int boton = 8;
const int luz = 6;
const int vel = 130;   // Velocidad normal del robot (0-255)
const int dist = 400;  // Distancia máxima para los sensores (en cm)
const int recto = 105;
const int agi = 170;  // Para giros de 90 grados a la izquierda
const int agd = 30;   // Para giros de 90 grados a la derecha
const int aci = 165;  // Pequeña corrección para alejarse de la pared derecha
const int acd = 45;   // Pequeña corrección para alejarse de la pared izquierda
const int aai = 140;
const int aad = 70;
int derecha = 0;
int uderecha = 0;
int izquierda = 0;
int uizquierda = 0;
float anculo = 0.0;
int giros = 0;
int so;
unsigned long rosamelano = -4000;  // Para asegurar que el primer giro pueda ocurrir
unsigned long tiempoUltimoArreglo = -150;
unsigned long utiempo = 0;
float stiempo = 0.0;
Servo giro;

NewPing sonar[2] = {
  NewPing(td, ed, dist),
  NewPing(ti, ei, dist)
};

void setup() {
  Serial.begin(9600);
  Serial.println("Iniciando sistema del robot...");
  Wire.begin();
  copio.initialize();
  giro.attach(servo);
  giro.write(recto);  // Ruedas rectas al inicio
  pixy.init();
  /*while(copio.testConnection()){
    Serial.println("Error al conectar giroscopio.");
    copio.initialize();
    delay(100);
  }*/
  Serial.println("Giroscopio conectado correctamente.");
  // Configurar pines de los motores
  pinMode(en, OUTPUT);
  pinMode(in1, OUTPUT);
  pinMode(in2, OUTPUT);
  pinMode(luz, OUTPUT);
  // Configurar pin del botón con resistencia pull-up interna
  pinMode(boton, INPUT_PULLUP);

  // Adjuntar el servo al pin correspondiente

  // Esperar a que se presione el botón para comenzar
  while (digitalRead(boton) == LOW) {
    delay(50);  // Pequeña pausa para no saturar el procesador
  }
  analogWrite(luz, 255);
  delay(1000);
  utiempo = millis();
}

void leerSensorDerecha() {
  uderecha = derecha;
  derecha = sonar[0].ping_cm();
  if (derecha == 0) {  // Si el sensor falla, usa la última lectura válida
    derecha = uderecha;
  }
  Serial.print("D: ");
  Serial.print(derecha);
  Serial.print(" ");
}

void leerSensorIzquierda() {
  uizquierda = izquierda;
  izquierda = sonar[1].ping_cm();
  if (izquierda == 0) {  // Si el sensor falla, usa la última lectura válida
    izquierda = uizquierda;
  }
  Serial.print("I: ");
  Serial.print(izquierda);
  Serial.print(" ");
}

void giroscopio() {
  copio.getMotion6(&ax, &ay, &az, &gx, &gy, &gz);
  stiempo = (millis() - utiempo) / 1000.0;
  utiempo = millis();
  float rad = gz / 131.0;
  anculo += (rad * stiempo);
  if (anculo > 180) anculo -= 360;
  if (anculo < -180) anculo += 360;
  Serial.print("Angulo: ");
  Serial.print(anculo);
}

void pelao(int num) {
int i;
for(i=0; i<num; i++){
  giroscopio();
  Serial.println();
  delay(100);
}
}

void pix() {
  int i;
  pixy.ccc.getBlocks();
  if (pixy.ccc.numBlocks) {
    so = pixy.ccc.blocks[0].m_signature;
  }
  delay(10);
}

void crotolamo() {
  giro.write(recto);
  analogWrite(en, vel);
  digitalWrite(in1, HIGH);
  digitalWrite(in2, LOW);
}

void lamocroto() {
  analogWrite(en, vel);
  digitalWrite(in1, LOW);
  digitalWrite(in2, HIGH);
}

void detener() {
  giro.write(recto);
  analogWrite(en, 0);
  digitalWrite(in1, LOW);
  digitalWrite(in2, LOW);
}

void girarDerecha() {
  Serial.println("Iniciando giro a la derecha...");
  digitalWrite(LED_BUILTIN, HIGH);
  analogWrite(en, vel);
  digitalWrite(in1, HIGH);
  digitalWrite(in2, LOW);
  /*if(izquierda > 40){
      giro.write(agi);
      delay(500);
  }
  while (anculo > -65) {
    giroscopio();
    Serial.println();
    giro.write(agd);
    delay(40);
  }*/
  pelao(15);
  while (anculo > -80) {
    giroscopio();
    Serial.println();
    lamocroto();
    Serial.print("Lamocroto ");
    giro.write(agi);
    delay(40);
  }
  anculo += 85.5;
  crotolamo();
  rosamelano = millis();
  giros++;
  Serial.print("Giro completado. Total de giros: ");
  Serial.println(giros);
}

void girarIzquierda() {
  Serial.println("Iniciando giro a la izquierda...");
  digitalWrite(LED_BUILTIN, HIGH);
  analogWrite(en, vel);
  digitalWrite(in1, HIGH);
  digitalWrite(in2, LOW);
  /*if(derecha > 40){
      giro.write(agd);
      delay(500);
  }
  while (anculo < 65) {
    giroscopio();
    Serial.println();
    giro.write(agi);
    delay(40);
  }*/
  pelao(15);
  while (anculo < 80) {
    giroscopio();
    Serial.println();
    lamocroto();
    Serial.print("Lamocroto ");
    giro.write(agd);
    delay(40);
  }
  anculo -= 85.5;
  crotolamo();
  rosamelano = millis();
  giros++;
  Serial.print("Giro completado. Total de giros: ");
  Serial.println(giros);
}


void loop() {
  crotolamo();
  Serial.print(giros);
  if (giros >= 12) {
    Serial.println("Trayecto finalizado.");
    delay(2500);  // Espera 2 segundos
    detener();
    while (true) {  // Bucle infinito para detener el programa
      // No hacer nada
    }
  }
  leerSensorIzquierda();
  leerSensorDerecha();
  giroscopio();
  pix();
  Serial.println();

  if (izquierda > 100 && ((millis() - rosamelano) > 4000)) {
    pelao(10);
    girarIzquierda();
  } else if (derecha > 100 && ((millis() - rosamelano) > 4000)) {
    pelao(10);
    girarDerecha();
  } else if (so == 1) {
    giro.write(acd);
    pelao(15);
    giro.write(aci);
    pelao(15);
    giro.write(recto);
    pelao(10);
    so = 0;
  } else if (so == 2) {
    giro.write(aci);
    pelao(15);
    giro.write(acd);
    pelao(15);
    giro.write(recto);
    pelao(10);
    so = 0;
  } else if (derecha < 20 && (millis() - tiempoUltimoArreglo > 150)) {
    Serial.println("Correccion -> Izquierda");
    giro.write(aci);
    delay(120);
    tiempoUltimoArreglo = millis();
    anculo -= 5;
  } else if (izquierda < 20 && (millis() - tiempoUltimoArreglo > 150)) {
    Serial.println("Correccion -> Derecha");
    giro.write(acd);
    delay(120);
    tiempoUltimoArreglo = millis();
    anculo += 5;
  } else if (anculo > 30) {
    while (anculo > 30) {
      giroscopio();
      Serial.println();
      giro.write(aad);
      delay(10);
      crotolamo();
    }
  } else if (anculo < -30) {
    while (anculo < -30) {
      giroscopio();
      Serial.println();
      giro.write(aai);
      delay(10);
      crotolamo();
    }
  } else {
    crotolamo();
  }
  delay(50);  // Pequeña pausa al final del bucle para estabilidad
}

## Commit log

2024-06-17 Add files via upload
    Commit de los planos en 3d del carro.
    [Planos carro.dwg]
2024-06-17 Update ServoTP1.txt
    En este archivo se encuentra el código el cual se encarga del funcionamiento del servo motor
2024-06-17 Create MotorTP1.text
    Aquí se encuentra el código para el funcionamiento del motor.
2024-06-17 Update and rename Planos to tp2/PlanosTP2.dwg
    [PlanosTP2.dwg]
2024-06-17 Create JuntocongiroTP1.txt
    Este código muestra como el carro realiza un giro hacia la derecha con un intervalo de tiempo de 5 segundos.
2024-06-21 Añadiendo archivos
    [Planos carro .dwg]
2024-06-29 Actualización 2 del carro
    [RCcar_2.stl, RCcar_3.stl, RCcar_4.stl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]
2024-07-12 Actualizacion
    Actualizacion 12 de julio, cambio de readme, arduino mega, codigo de arduino mega. Se añadió un codigo provicional para un futuro uso de un Raspberry PI
2024-07-12 Codigo .ino
    Se optimizó el codigo (se borraron algunas funciones comentadas)
2024-07-15 Actualización
    Se actualizó el READMI, se agregó readmi en ingles, se agregó el nuevo model del carro.
    [Chassis_DOWN.STL, Chassis_UP.STL, Direccion nueva.stl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]
2025-06-09 Doc Update
    Change the place of the docs 2024 and make the new folder for 2025
    [Chassis_DOWN.STL, Chassis_UP.STL, Direccion nueva.stl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]
2025-06-09 Doc Upgrade
    Create the new code for Sonicar
    [Chassis_DOWN.STL, Chassis_UP.STL, Direccion nueva.stl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]
2025-06-10 Doc Update
    Deleted the models of car #1 and #2 2024.
    Create new carpet for model of car 2025
    [Chassis_DOWN.STL, Chassis_UP.STL, Direccion nueva.stl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]
2025-06-10 Temp changes
    Models of car #1 2024 on carpets temporally
    [Planos carro #1.dwg, RCcar_2.stl, RCcar_3.stl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]
2025-06-10 Doc Update
    Deleted the codes of car 2024 .py and arduino
2025-06-24 Update README.md
    New image, table, and information for motor dc lego.
2025-06-24 Update README.md
    New table, image, and information about the motor driver on Readmi.
2025-06-24 Update README.md
    New image, table, and information about the servo motor on Readmi.
2025-06-24 Update README.md
    New image, table, and information about the arduino mega on the Readmi.
2025-06-24 Update README.md
    New image for arduino mega on the Readmi.
2025-06-24 Update README.md
    Fix images of servo motor and arduino on the Readmi.
2025-06-24 Update README.md
    Fix image of servo motor on the Readmi.
2025-06-24 Update README.md
    Fix image of the servo motor on the Readmi.
2025-06-24 Update README.md
    New image, table, and information for laser sensor on the Readmi.
2025-06-24 Update README.md
    New image, table, and information for ultrasonic sensor on the Readmi.
2025-06-24 Update README.md
    New image, table, and information for camera HuskyLens on the Readmi.
2025-06-24 Update README.md
    Fix image of camera HuskyLens on the Readmi.
2025-06-25 Doc Update
    New parts of the code of the DC motor and servo motor to the Readmi.
2025-06-26 Doc Update
    New file of the chassis of the car.
    [chasisprototipo2.stl]
2025-06-27 Doc Update
    New images of the internal and external measurements of the parts on 3d of the chassis of the car 2025.
2025-06-27 Doc Update
    New top view of the chassis on the file others/images for the Readmi.
2025-06-27 Update README.md
    New images of the chassis (internal and external measurements) on the Readmi.
    New image of the .stl of the chassis on the Readmi.
2025-07-05 Update README.md
    Update and change the information about the camera on the Readmi.
    Change from the huskylens camera to the Pixy2 camera.
